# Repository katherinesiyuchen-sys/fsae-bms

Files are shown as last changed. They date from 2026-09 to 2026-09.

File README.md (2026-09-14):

# fsae-bms

*Doing this for the love of the game 🏎️*

Centralized battery management board for one **6S segment** of Energus 1s4p Li-ion modules.

## Cell voltage

Six cells in series stack up. Only cell 1 has a terminal at 0 V:

```
cell 6   18.0 V ── 21.6 V
cell 1      0 V ──  3.6 V
```

An ADC measures relative to its own ground and reads 0–3.3 V. Cell 6's top sits at 21.6 V, so we cannot wire it to a pin and measuring both ends and subtracting means finding a 3.6 V answer from two ~20 V readings, with all the error from both landing on the difference.

**A flying capacitor removes the pedestal mechanically.** Two ADG1408 muxes, addressed together with inputs offset by one tap, connect a 1 µF capacitor across the selected cell. The mux then disconnects both ends — the capacitor holds the cell's voltage with no memory of its former potential — and a second mux state presents it to the ADC as an ordinary ground-referenced source.

All six cells travel one signal path, so there is **one** gain error and **one** offset, common to all of them. In the cell-to-cell comparison balancing depends on, a common error largely cancels.

Rejected: a divider stack (error from both taps lands in full on a 3 V result), and six high-common-mode difference amplifiers (6× cost, six independent gain errors to trim).

### Channel map

Each mux has 8 channels; six cells use six, and the spare two do real work.

| Address | U1 — cap top | U2 — cap bottom | Phase |
|---|---|---|---|
| 0–5 | `CELL2`–`CELL7` | `CELL1`–`CELL6` | charge from cell 1–6 |
| 6 | `SELFTEST` | `GNDA` | known voltage through the chain |
| 7 | ADC divider | `GNDA` | read cap into ADC |

Address 7 *is* the transfer switch, so no second high-voltage switch is needed, and break-before-make — the property the mux was chosen for — protects the transfer too.
Address 6 verifies mux, capacitor, divider and reference every scan, before a cell reading is trusted. `SELFTEST` derives from `+3.3VA`, **not** `VREF`, so a reference failure cannot hide itself.

## Temperature 

The Energus module's built-in sensor is a **temperature-variable voltage shunt reference**, behaving like a zener whose voltage falls with temperature.

| Property | Consequence |
|---|---|
| Needs a **680 Ω pull-up**, not a divider | ~2.2 mA bias per channel |
| 2.44 V @ −40 °C → 1.30 V @ +120 °C, non-linear | datasheet lookup table, no β equation |
| **Galvanically isolated** from cell terminals | reads ground-referenced — no mux, no level shift |
| 4 sensors per module, analogue-OR'd | reports the module hot spot — 100 % coverage against a 30 % requirement |
| Shunt reference, not a ratio | reading largely immune to rail variation |

Six channels diode-OR into `TEMP_HOT`. Because sensor voltage *falls* with temperature, the hottest module is the lowest voltage, so a common-anode Schottky array extracts the minimum and one comparator watches all six.

**The diode drop is an error and it sets the threshold.** `TEMP_HOT` = lowest sensor + V_f, about 0.2 V at 154 µA, varying ±50 mV. At −11 mV/°C that's ±4.5 °C. So the hardware trip is aimed at **57 °C** to absorb the spread, and firmware, which reads all six channels individually, owns the precise per-module limit. Layered by design: the comparator is the backstop that works with firmware dead.

```
threshold  1.534 V (57 C) + 0.2 V Vf  =  1.734 V
divider    R18 662R / R19 1.50k from VREF
check      1.5 / 2.162 x 2.5  =  1.734 V
```

`TSENSE_RTN` returns to `GNDA`, not `GND`: you're measuring a voltage across the sensor relative to its own return, and the ADC measures relative to `VSSA`. The ~13 mA of sensor current in the analog ground is DC, so it's a fixed offset rather than noise.

---

## Protection 

A hung microcontroller that hasn't noticed an overvoltage is *indistinguishable* from a healthy one that sees nothing wrong. Both are silent. So the trip cannot depend on code
executing and the rules agree: the shutdown circuit must be latched open by non-programmable logic, resettable only by a person at the vehicle. **SW1, never a GPIO.**

| Source | Threshold | At | Gated |
|---|---|---|---|
| Overvoltage | 2.096 V | 4.192 V cell | address 7 only |
| Undervoltage | 1.246 V | 2.493 V cell | address 7 only |
| Overtemperature | 1.734 V | 57 °C | continuous |
| Watchdog timeout | ~200 ms | kicked every 20 ms | continuous |

`VCELL` is only a real cell voltage during the read slot — every other slot the divider
node is mid-transfer. So the voltage comparators are gated by an address decode, and one
gate does the whole job:

```
NOR(/ADDR7, VFAULT_N)  =  ADDR7 . fault
```

Both signals are active-low, and NOR is the AND of two active-low inputs.

All four thresholds derive from `VREF` — the same reference the ADC's scale is corrected against — so hardware trip points and firmware measurements can never disagree about what 4.2 V means.

**The fail-safe is structural.** The relay's normally-open contact sits in the shutdown circuit, held closed only while the latch says healthy *and* 12 V is present. A fault, a dead latch, a lost rail, an undriven gate. Every one gives coil de-energized, contact open, circuit broken. Q1's gate pulldown guarantees the last of those.

---

## Balancing

Passive dissipative, one optocoupler and one BSS138 per cell. The optocoupler solves a level-shift problem: cell 6's FET source sits ~21 V above ground, and a MOSFET switches on V_GS, gate voltage relative to *its own source*. A ground-referenced 3.3 V drive reads as −21 V to that gate.

```
LED     (3.3 - 1.2) / 470R  =  4.5 mA
opto    CTR ~50%            ->  ~2.2 mA available
gate    4.2 V / 101k        =  42 uA needed      (50x margin)
        -> phototransistor saturates, Vgs ~ 3.96 V

bleed   4.2 V / 100R  =  42 mA
        0.176 W per cell  ·  1.06 W all six  ·  1206 rated 0.25 W
```

100 Ω rather than 50 Ω halves current and dissipation — consistent with the argument below that heat is the binding constraint, not balance time. Shedding ~200 mAh at 42 mA takes about five hours, which is normal: balancing happens on the charger between sessions, not on track.

### Active balancing was evaluated and rejected

Without a dedicated controller the options are a switched-capacitor shuttle (a signal mux can't carry useful balance current, so it needs a second HV switch matrix whose timing must never overlap the first), adjacent-cell inductive buck-boost (five half-bridges with isolated gate drive, moving charge one hop at a time), or multi-winding flyback (custom magnetics).

Against that: active balancing recovers a fraction of the *imbalance* order 1–2 % of capacity at ~80 % transfer efficiency. And the problem passive balancing actually causes in a sealed accumulator is **heat**, better solved by limiting how many cells bleed at once. 

What would change the answer: a longer event, a thermally-limited pack, or a production vehicle where round-trip efficiency compounds over thousands of cycles.

---

### Buses

```
CELL[1..7]    cell taps -> frontend, balance
BAL_EN[1..6]  mcu -> balance
TSENSE[1..6]  J2 -> temp
TEMP[1..6]    temp -> mcu
FE_CTL        {MUX_A0 MUX_A1 MUX_A2 MUX_EN}
PROT          {WDT_KICK FAULT_N}
CAN           {CAN_TX CAN_RX}
SWD           {SWDIO SWCLK SWO NRST}
```

Bus aliases live in `feb-bms.kicad_pro`, so open the **project**, not individual sheets, or
they won't resolve.

## Key parts

| Ref | Part | Role | Datasheet |
|---|---|---|---|
| U1, U2 | ADG1408YRUZ | 8:1 analog mux, break-before-make | [ADI](https://www.analog.com/media/en/technical-documentation/data-sheets/ADG1408_1409.pdf) |
| U4 | LM339 | quad comparator, open collector | [ST](https://www.st.com/resource/en/datasheet/lm139.pdf) |
| U3/U5/U6/U7/U8/U11 | 74LVC1G10 / 1G02 / 1G32 | gating and latch | [TI](https://www.ti.com/lit/ds/symlink/sn74lvc1g02.pdf) |
| U9 | TPS3823-33 | watchdog supervisor | [TI](https://www.ti.com/lit/ds/symlink/tps3823.pdf) |
| U10 | ADR4525 | 2.500 V reference | [ADI](https://www.analog.com/media/en/technical-documentation/data-sheets/ADR4520_4525_4530_4533_4540_4550.pdf) |
| U18 | STM32F446RETx | LQFP64 | [ST](https://www.st.com/resource/en/datasheet/stm32f446re.pdf) |
| U19 | TJA1051T/3 | CAN transceiver, VIO = 3.3 V | [NXP](http://www.nxp.com/docs/en/data-sheet/TJA1051.pdf) |
| U20 | AP63203WU | 12 V → 5 V buck | [Diodes](https://www.diodes.com/assets/Datasheets/AP63200-AP63201-AP63203-AP63205.pdf) |
| U21 | MIC5219-3.3 | 5 V → 3.3 V LDO, low noise | [Microchip](http://ww1.microchip.com/downloads/en/DeviceDoc/MIC5219-500mA-Peak-Output-LDO-Regulator-DS20006021A.pdf) |
| U22 | TPS61040 | 12 V → 28 V boost | [TI](http://www.ti.com/lit/ds/symlink/tps61040.pdf) |
| Q1, Q2, Q3–Q8 | BSS138 | relay / lamp / balance | [onsemi](https://www.onsemi.com/pub/Collateral/BSS138-D.PDF) |
| Q9 | AO3401A | reverse-polarity blocker | [AOS](http://www.aosmd.com/pdfs/datasheet/AO3401A.pdf) |
| U12–U17 | LTV-817S | balance gate drive, isolated | [Liteon](http://www.us.liteon.com/downloads/LTV-817-827-847.PDF) |
| D3–D5 | BAT54A | diode-OR, common anode | [Diodes](http://www.diodes.com/_files/datasheets/ds11005.pdf) |
| D10 | SMAJ16A | load-dump clamp, unidirectional | [Littelfuse](https://www.littelfuse.com/media?itemid=75e32973-b177-4ee3-a0ff-cedaf1abdb93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) |
| K1 | SPDT relay | NO contact in the SDC | — |

## Compliance

Requirements below are from the **Formula Student 2026 rules v1.1**. The clause numbers
still need re-deriving from the FSAE rulebook — same requirements, different numbering.

| Requirement | Where it lands |
|---|---|
| Measure all cell voltages, TS current, ≥30 % of cell temps | 6 cells scanned; module sensors cover 100 %. **TS current is not on this board** — open question whether a segment board carries it |
| Max cell temp 60 °C or datasheet, whichever lower | 45 °C is binding while charging |
| Open SDC on persistent fault: >500 ms voltage, >1 s temp | 145 ms scan |
| Red latching cockpit "AMS" lamp | driven from the latch, not firmware |
| Loss of a measurement connection must open SDC | self-test slot + implausible-reading detection |
| Faults individually injectable for inspection | break-in header — **to add** |
| SDC latched by non-programmable logic, manual reset | SR latch + SW1 |
| De-energized state opens SDC | NO relay contact throughout |

## Opening this

KiCad 10.0.3. Open **`feb-bms.kicad_pro`**.

## Presentation

Full deck: [BMS.pdf](BMS.pdf) · source: [BMS.pptx](BMS.pptx)

| | |
|---|---|
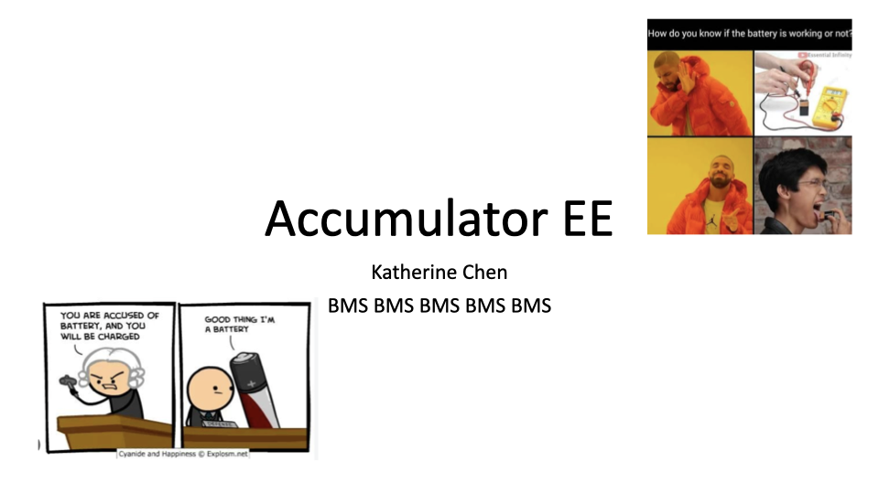
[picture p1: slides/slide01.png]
1 – Title
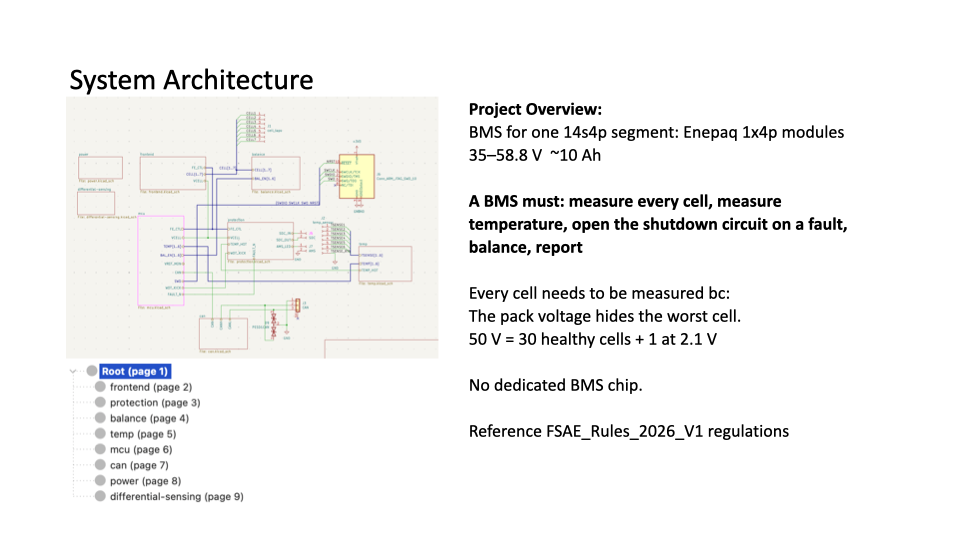
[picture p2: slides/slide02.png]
2 – System architecture
|  |  |
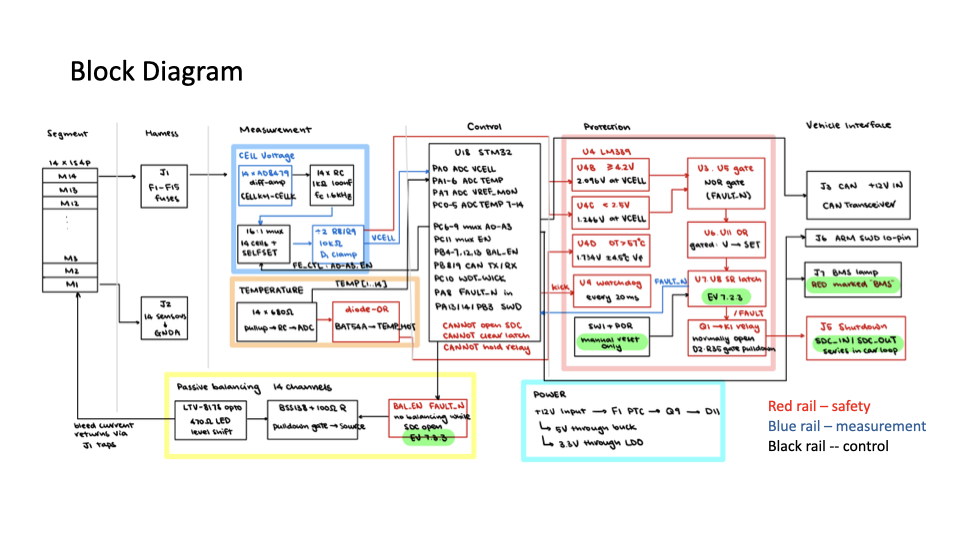
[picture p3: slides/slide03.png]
3 – Block diagram
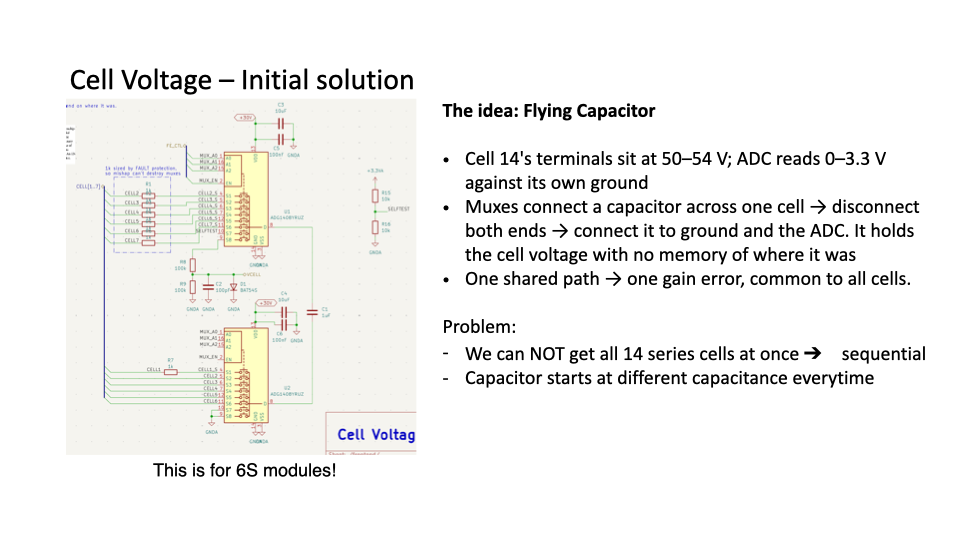
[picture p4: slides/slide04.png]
4 – Cell voltage: flying capacitor
|  |  |
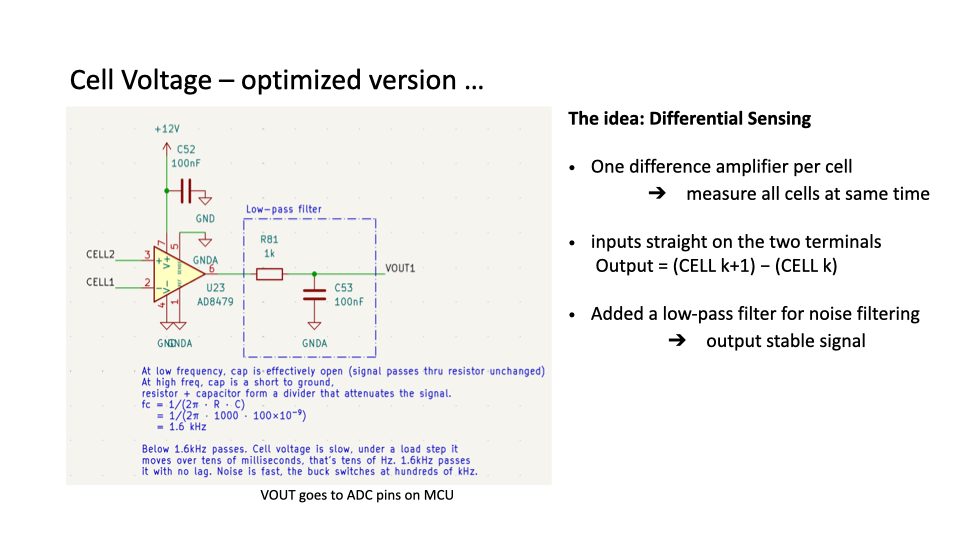
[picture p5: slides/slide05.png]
5 – Cell voltage: differential amplifier
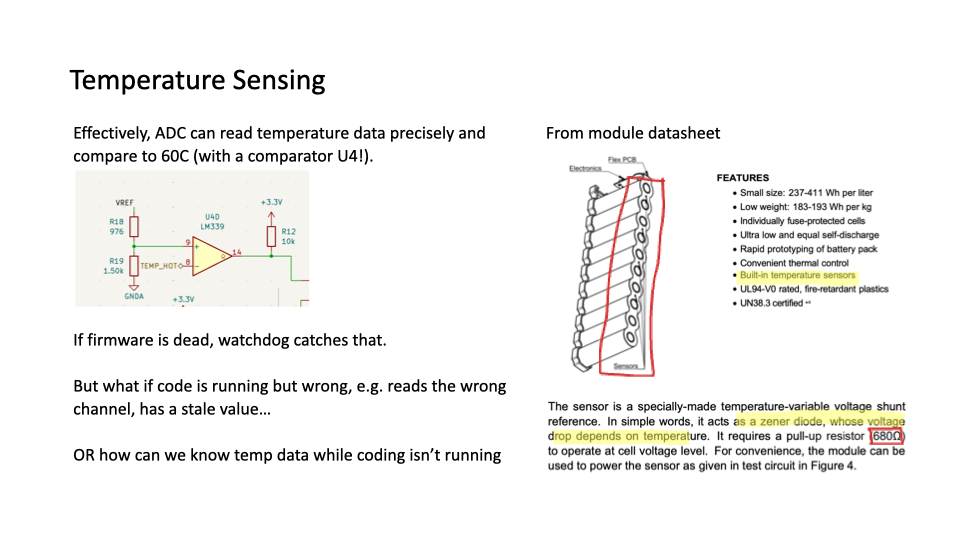
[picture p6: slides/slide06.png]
6 – Temperature sensing
|  |  |
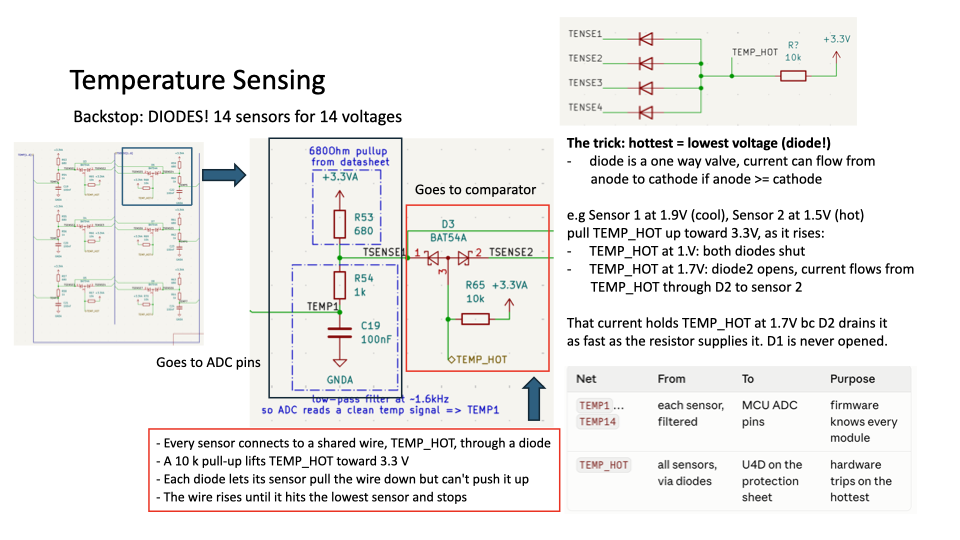
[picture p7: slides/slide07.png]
7 – Temperature sensing: diode-OR
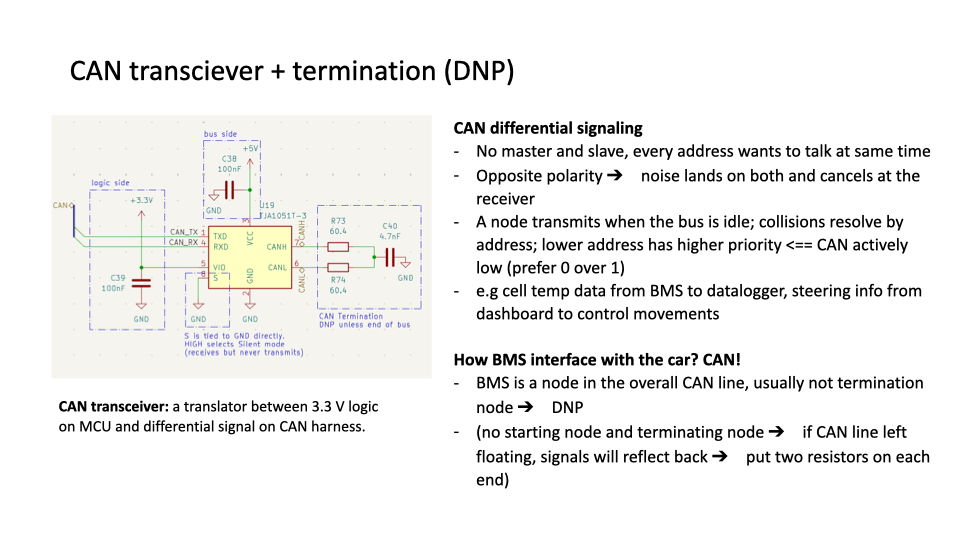
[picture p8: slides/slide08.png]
8 – CAN transceiver + termination
|  |  |
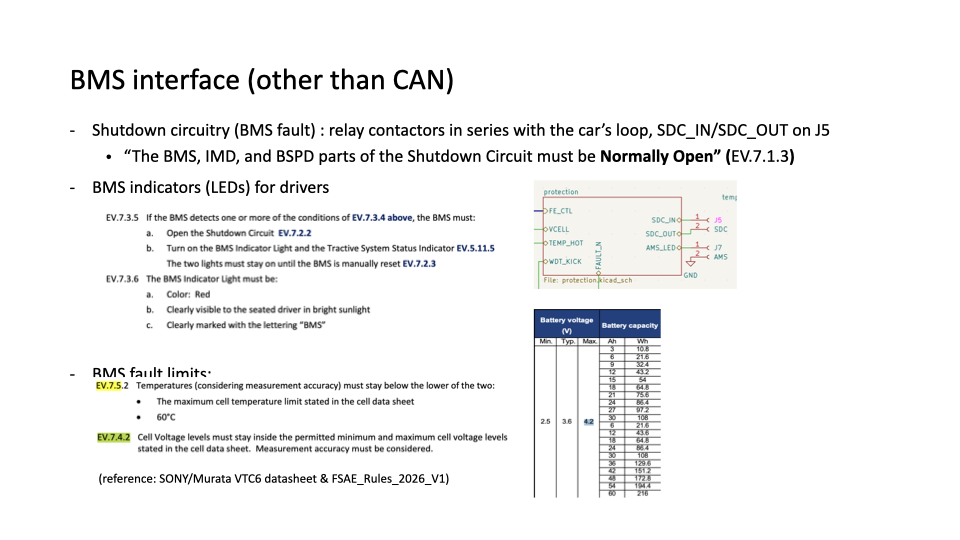
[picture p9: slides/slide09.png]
9 – BMS interface to the car
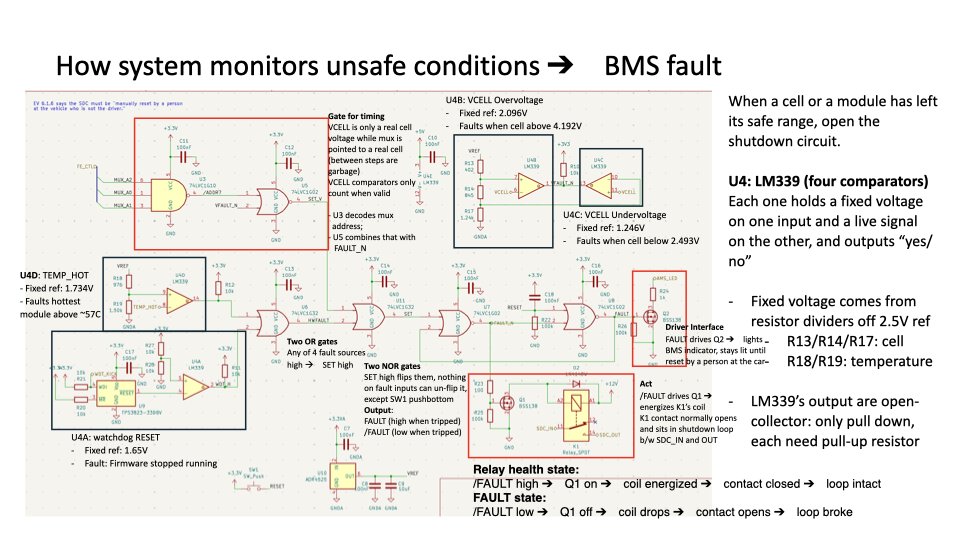
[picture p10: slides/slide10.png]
10 – Unsafe-condition monitoring → BMS fault
|  |  |
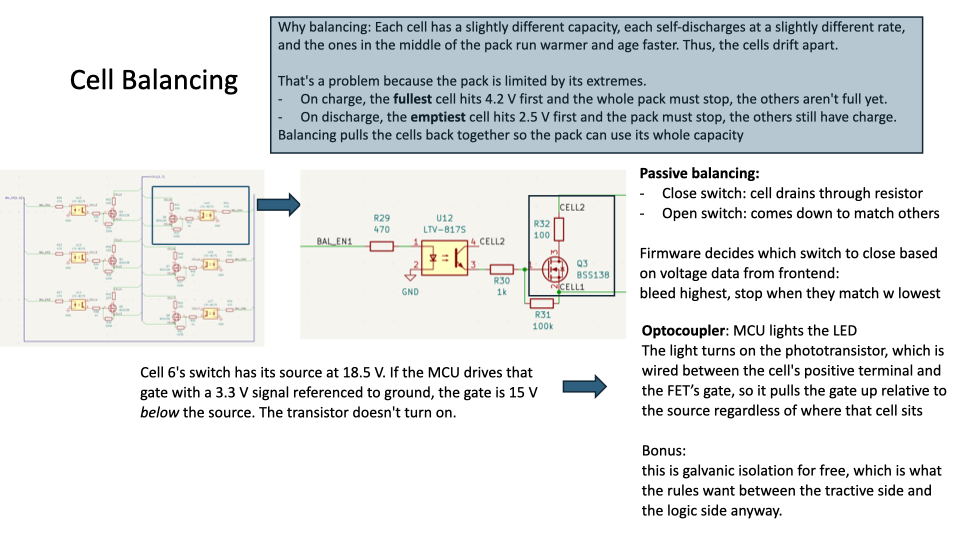
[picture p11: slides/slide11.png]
11 – Cell balancing
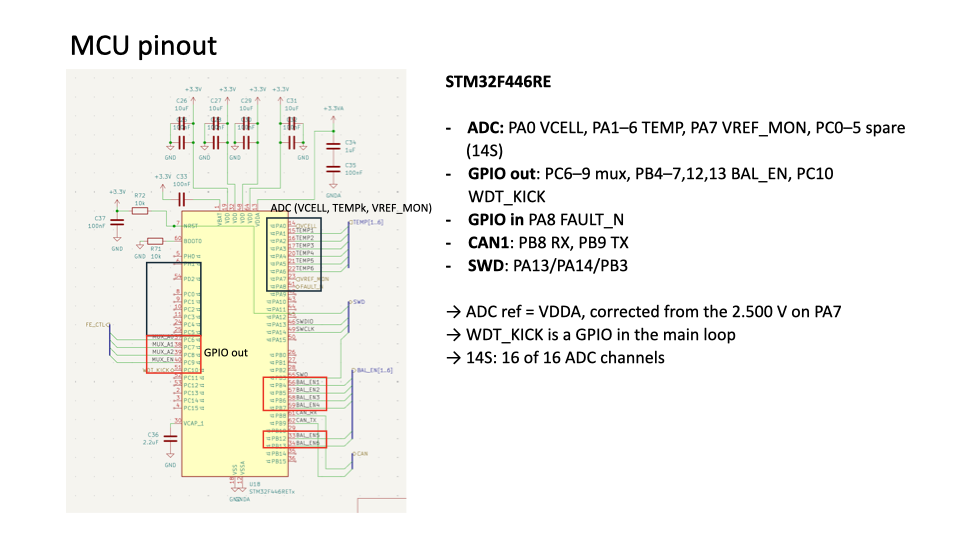
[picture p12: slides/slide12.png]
12 – MCU pinout
|  |  |
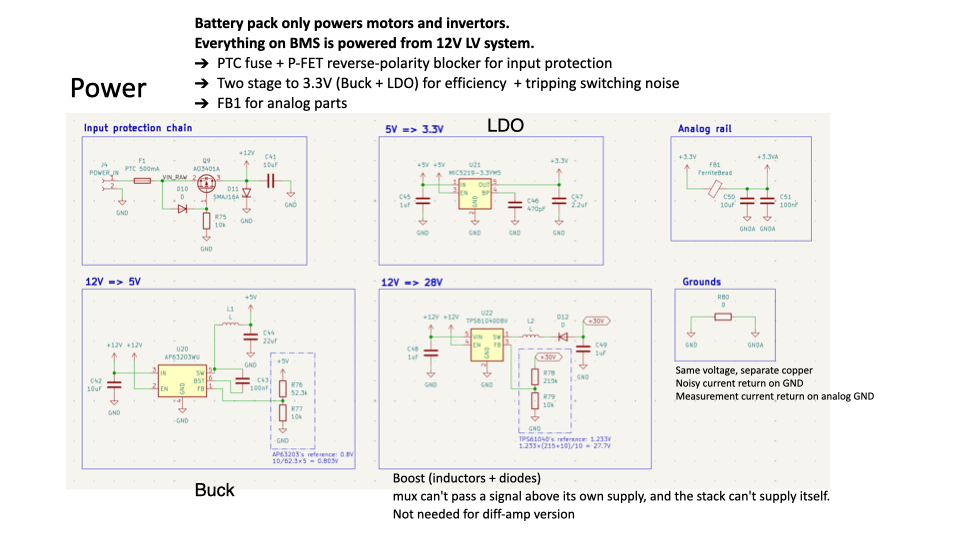
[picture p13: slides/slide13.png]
13 – Power
|  | |

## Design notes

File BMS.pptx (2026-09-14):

## Accumulator EE

Katherine Chen
BMS BMS BMS BMS BMS

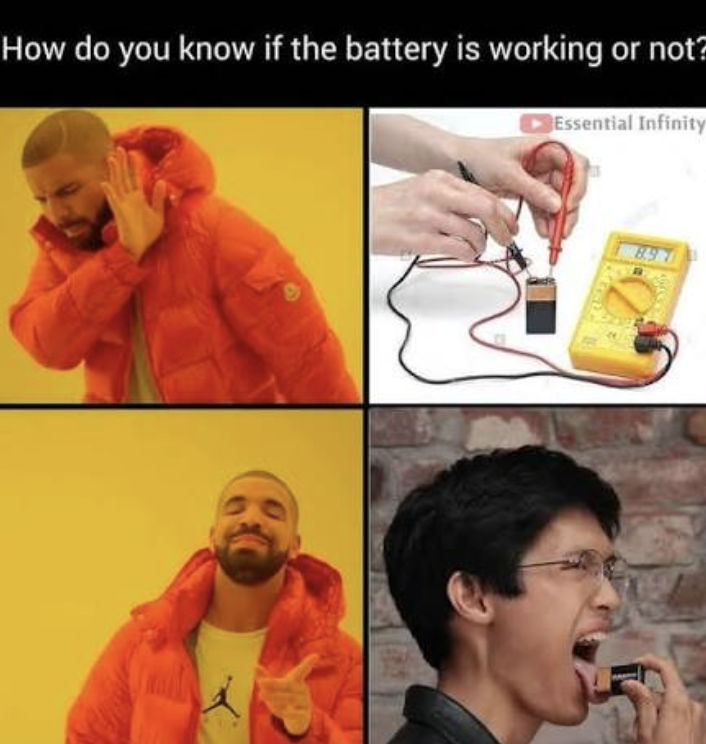
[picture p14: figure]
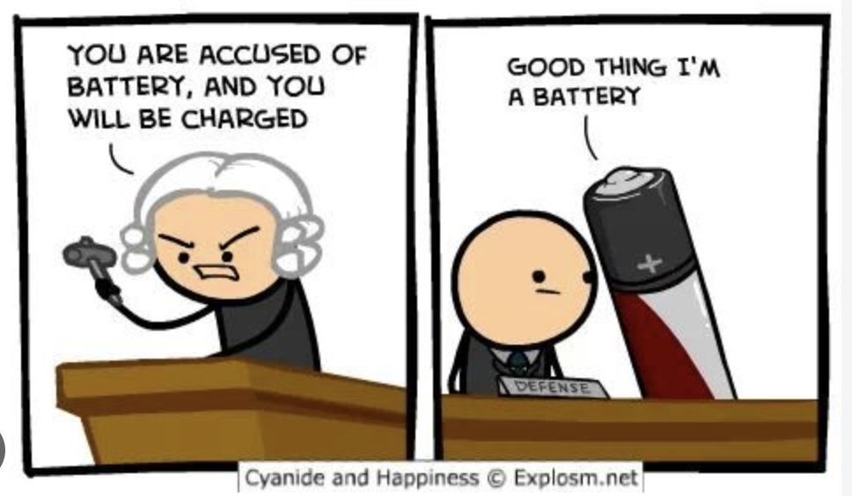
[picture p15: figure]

## System Architecture

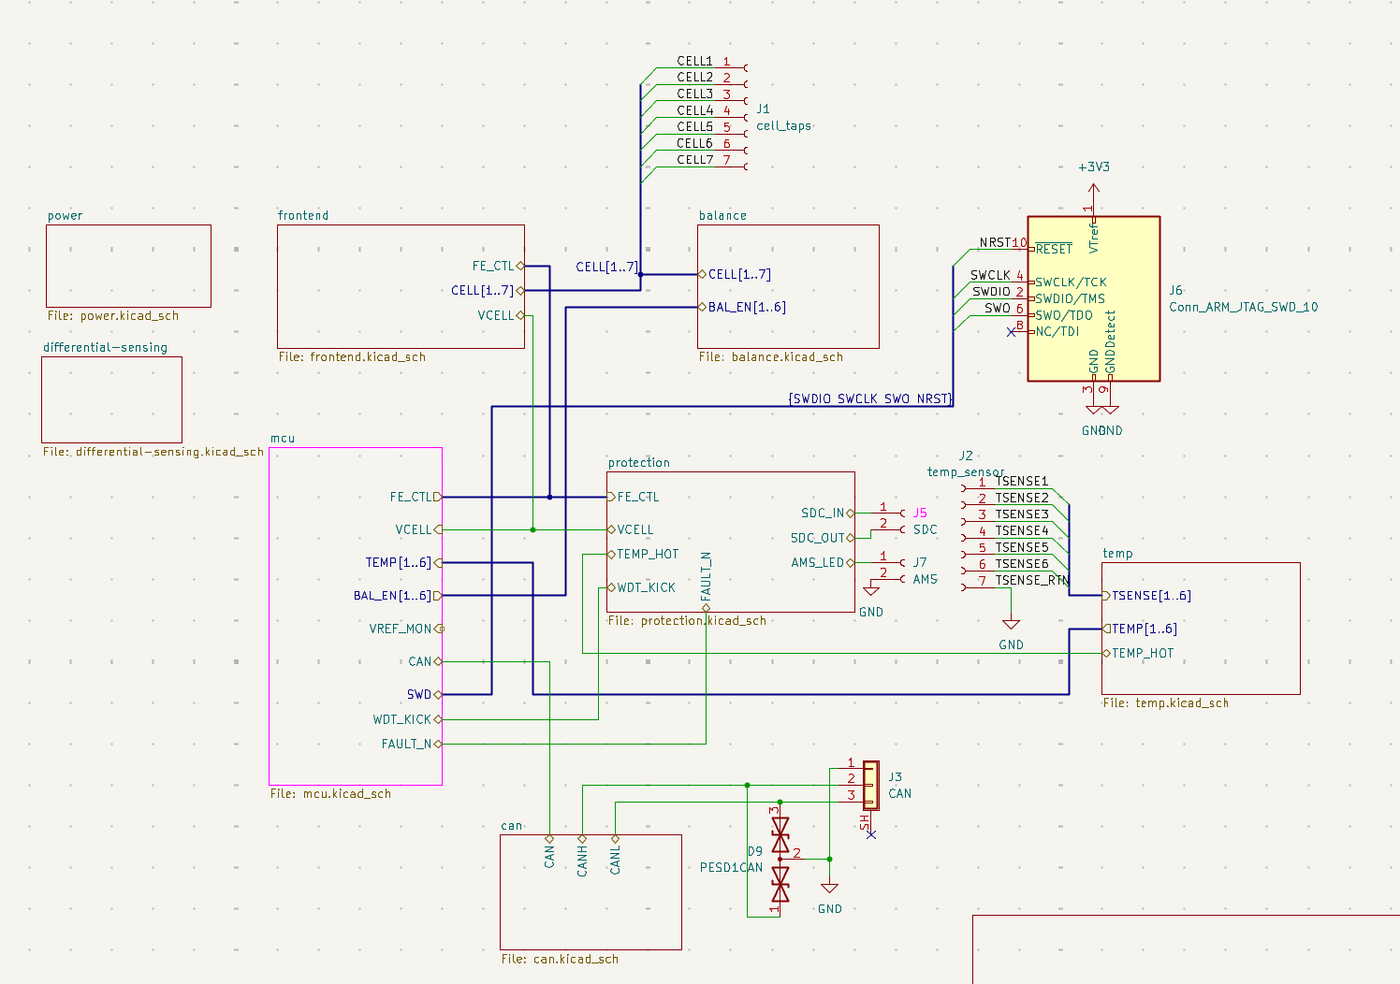
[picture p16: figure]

Project Overview:
BMS for one 14s4p segment: Enepaq 1x4p modules 35–58.8 V ~10 Ah
A BMS must: measure every cell, measure temperature, open the shutdown circuit on a fault, balance, report
Every cell needs to be measured bc:
The pack voltage hides the worst cell.
50 V = 30 healthy cells + 1 at 2.1 V
No dedicated BMS chip.
Reference FSAE_Rules_2026_V1 regulations

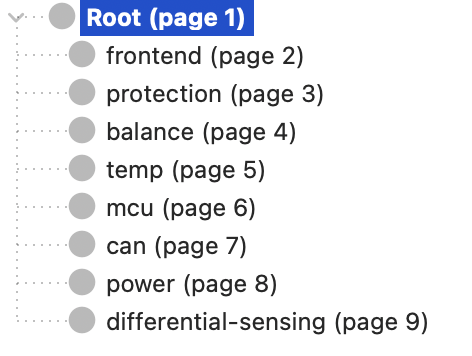
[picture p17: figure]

## Block Diagram

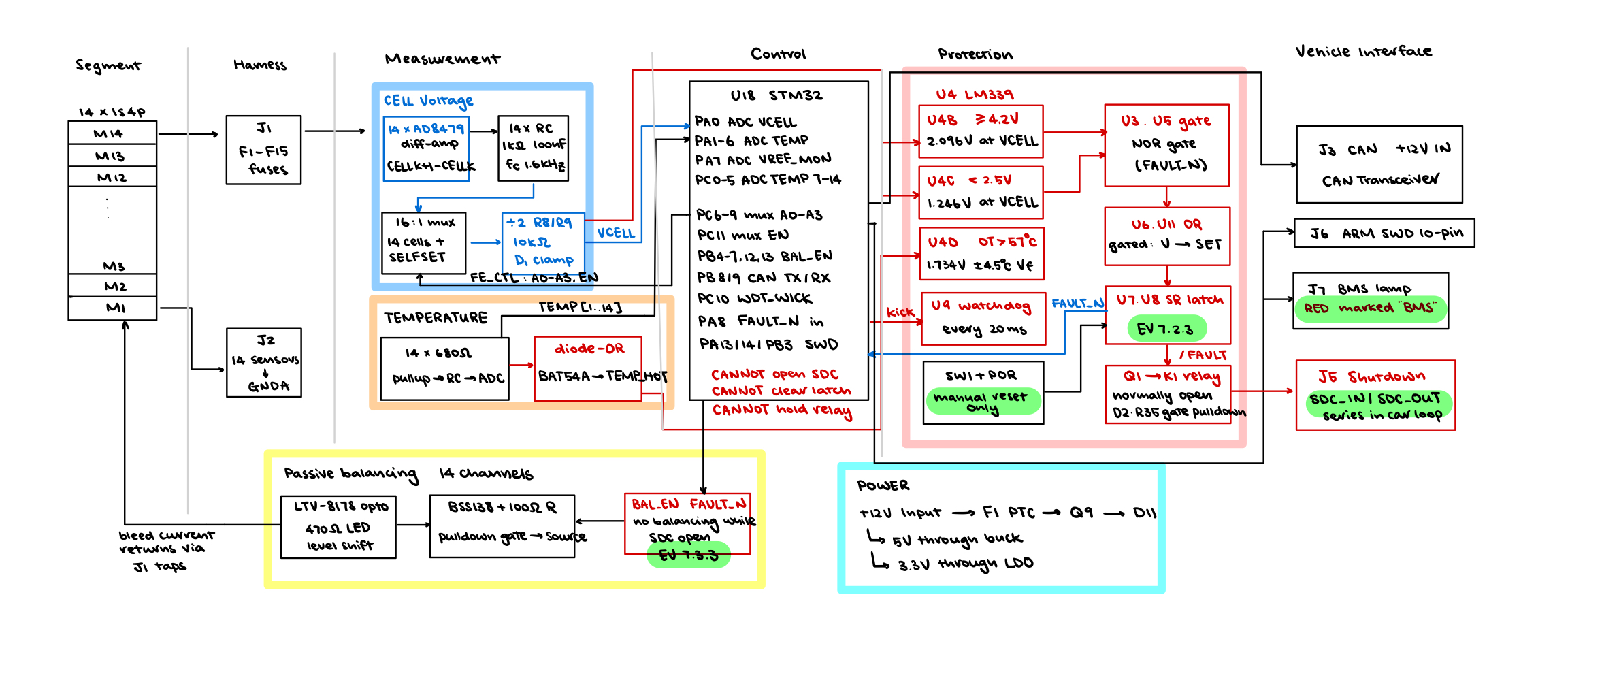
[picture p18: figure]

Red rail – safety
Blue rail – measurement
Black rail -- control

## Cell Voltage – Initial solution

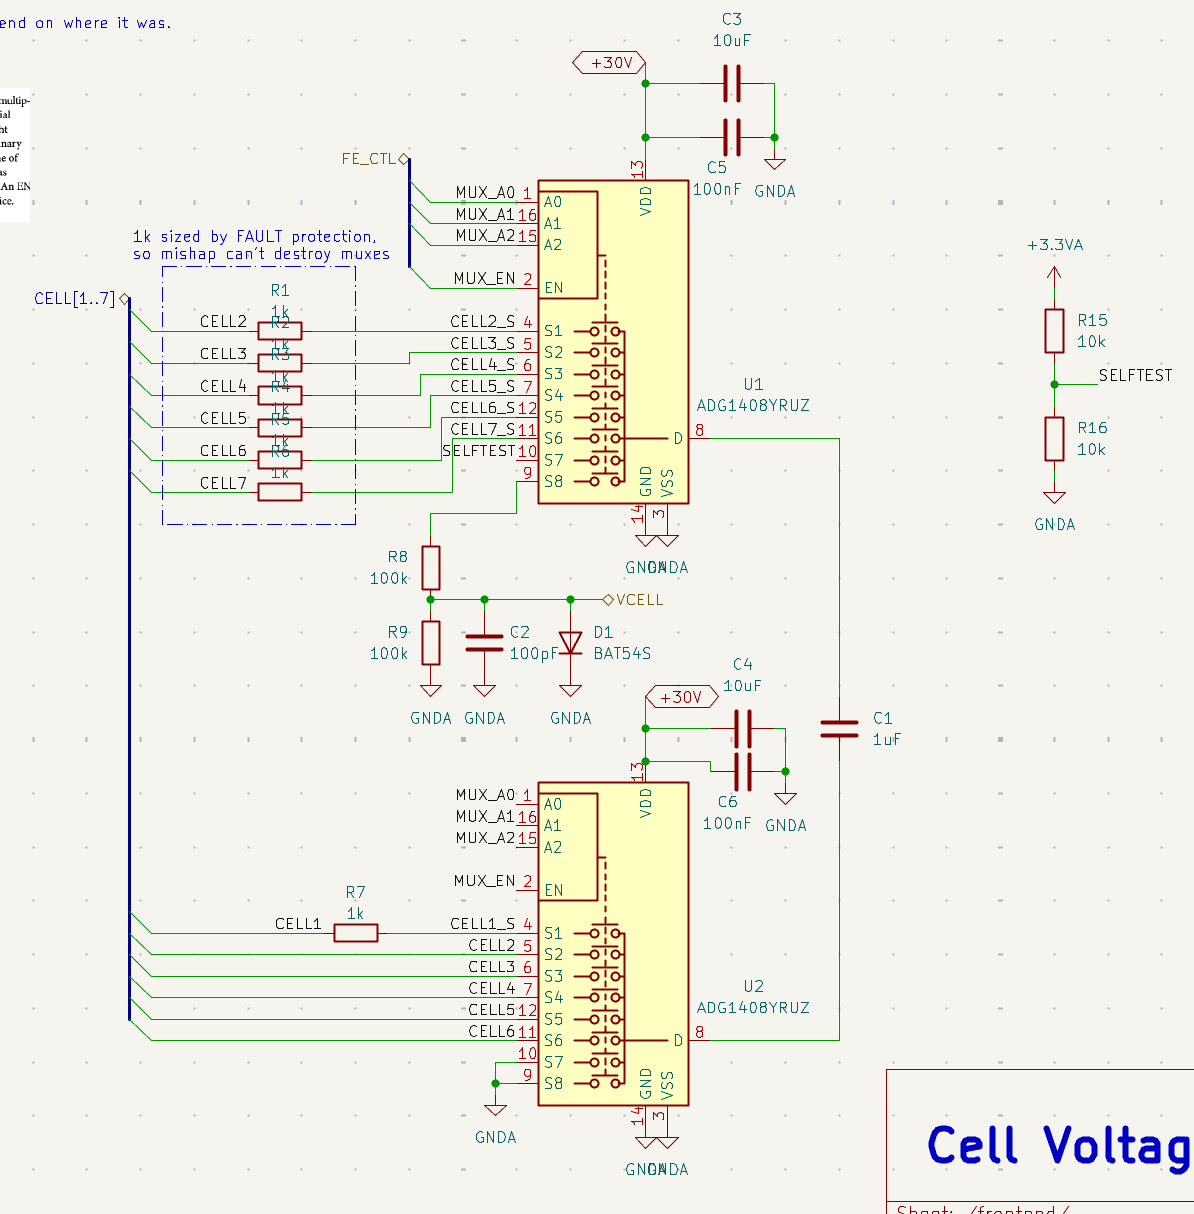
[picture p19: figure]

This is for 6S modules!

The idea: Flying Capacitor
- Cell 14's terminals sit at 50–54 V; ADC reads 0–3.3 V against its own ground
- Muxes connect a capacitor across one cell → disconnect both ends → connect it to ground and the ADC. It holds the cell voltage with no memory of where it was
- One shared path → one gain error, common to all cells.
Problem:
- We can NOT get all 14 series cells at once → sequential
- Capacitor starts at different capacitance everytime

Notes: multiplexer - selector switch

## Cell Voltage – optimized version …

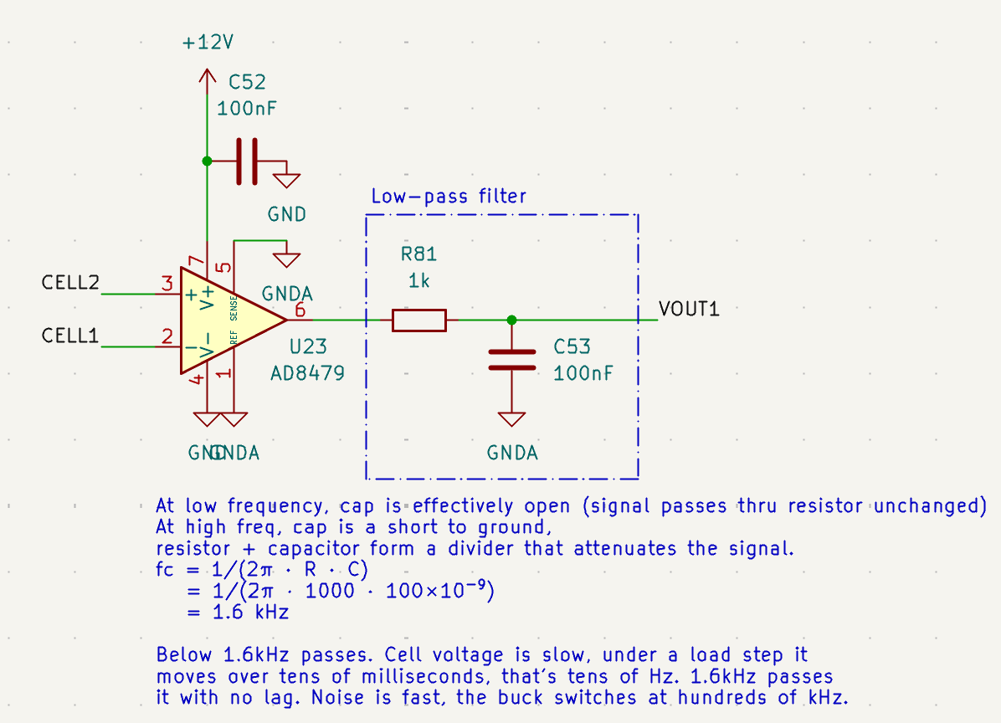
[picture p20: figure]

The idea: Differential Sensing
- One difference amplifier per cell
→ measure all cells at same time
- inputs straight on the two terminals
Output = (CELL k+1) − (CELL k)
- Added a low-pass filter for noise filtering
→ output stable signal

VOUT goes to ADC pins on MCU

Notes:
There are two ways to measure voltage:
Single ended: measure one point against ground -- ADC pins
Differential: measure the gap between two points, and don’t care about where either one is relative to ground

## Temperature Sensing

Effectively, ADC can read temperature data precisely and compare to 60C (with a comparator U4!).
If firmware is dead, watchdog catches that.
But what if code is running but wrong, e.g. reads the wrong channel, has a stale value…
OR how can we know temp data while coding isn’t running

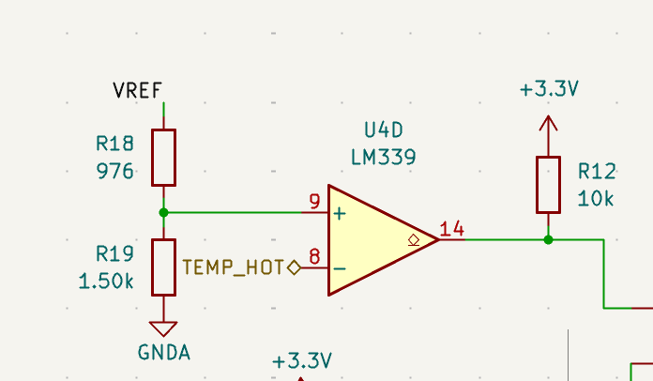
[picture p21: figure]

From module datasheet

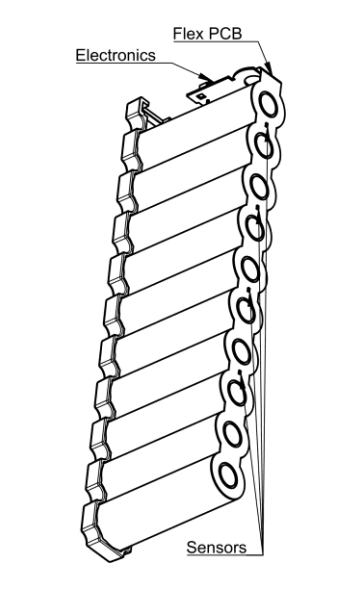
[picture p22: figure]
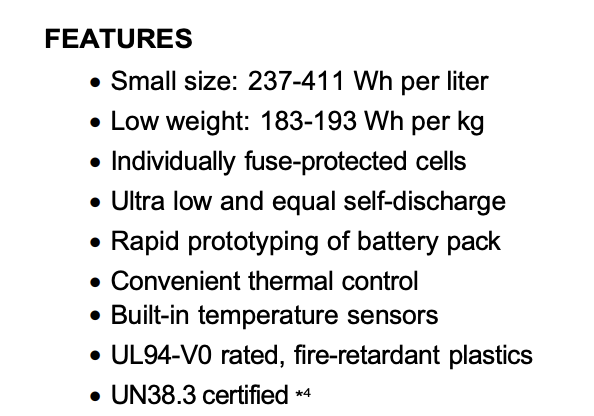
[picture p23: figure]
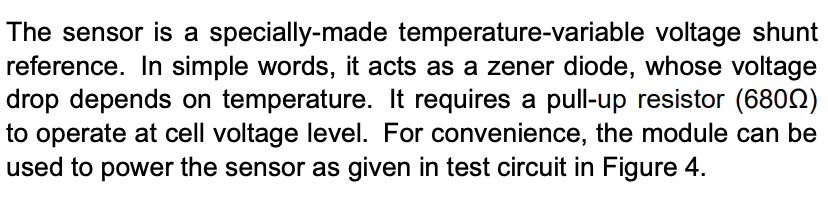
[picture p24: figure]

## Temperature Sensing

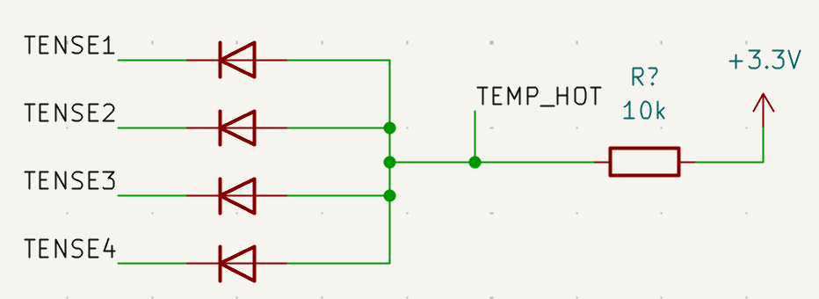
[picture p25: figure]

The trick: hottest = lowest voltage (diode!)
- diode is a one way valve, current can flow from
anode to cathode if anode >= cathode
e.g Sensor 1 at 1.9V (cool), Sensor 2 at 1.5V (hot)
pull TEMP_HOT up toward 3.3V, as it rises:
- TEMP_HOT at 1.V: both diodes shut
- TEMP_HOT at 1.7V: diode2 opens, current flows from
TEMP_HOT through D2 to sensor 2
That current holds TEMP_HOT at 1.7V bc D2 drains it
as fast as the resistor supplies it. D1 is never opened.

Backstop: DIODES! 14 sensors for 14 voltages

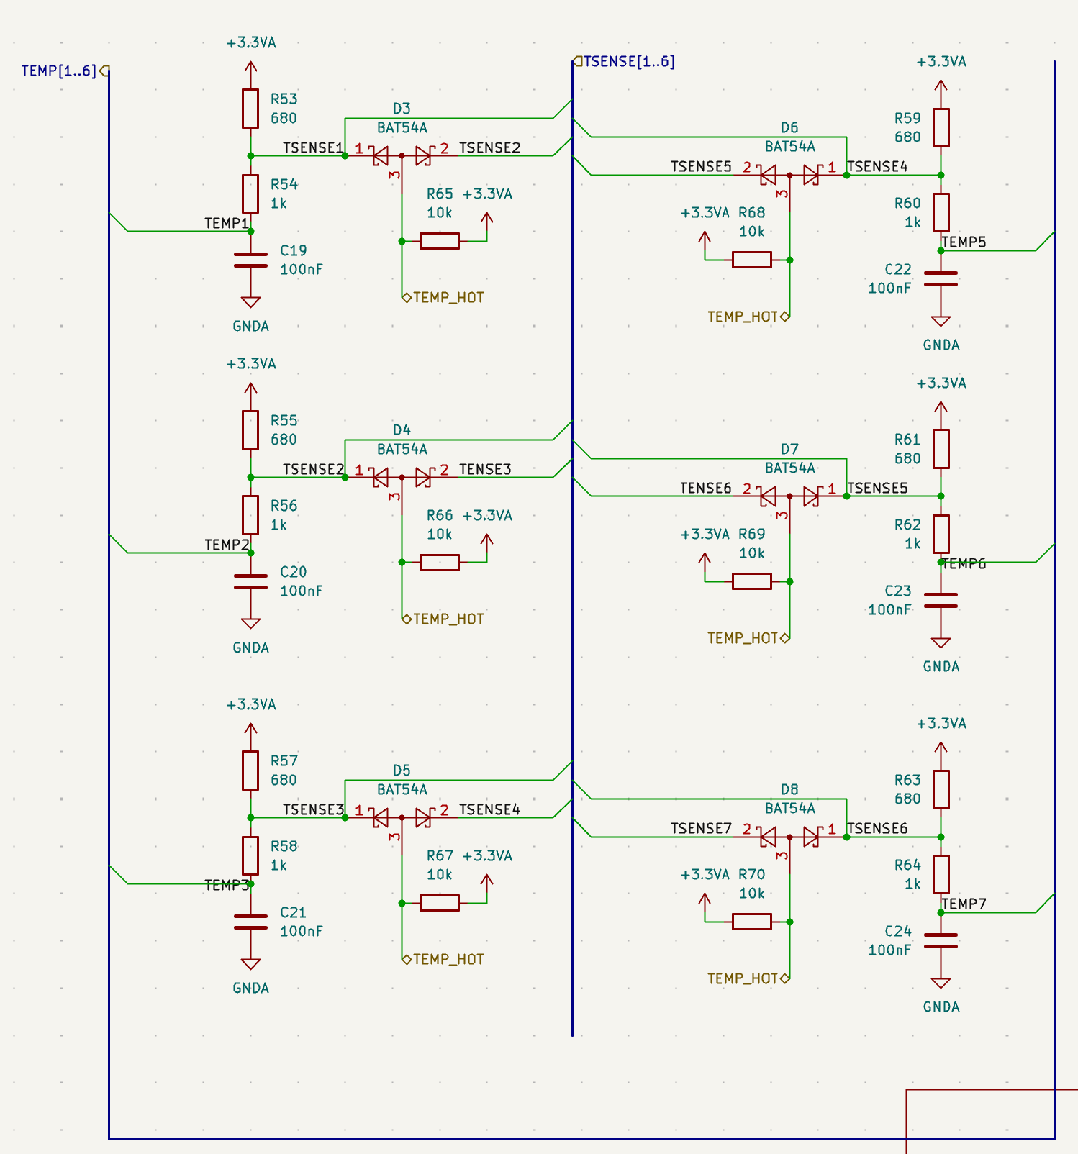
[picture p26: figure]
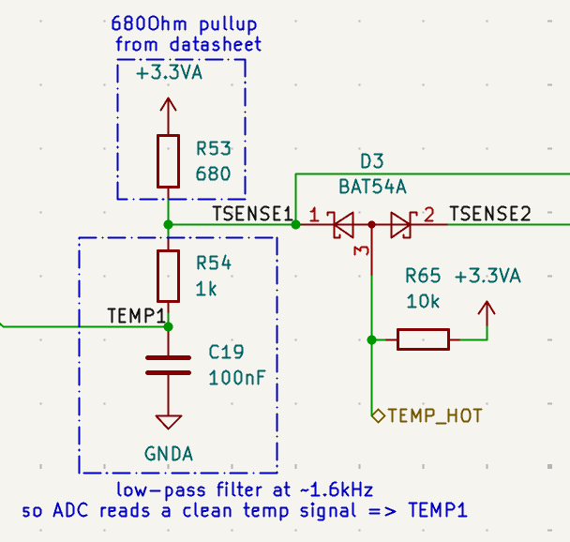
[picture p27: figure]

Goes to comparator

Goes to ADC pins

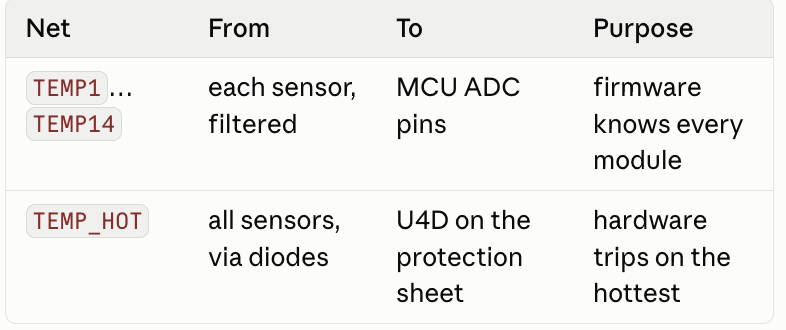
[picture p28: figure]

- Every sensor connects to a shared wire, TEMP_HOT, through a diode
- A 10 k pull-up lifts TEMP_HOT toward 3.3 V
- Each diode lets its sensor pull the wire down but can't push it up
- The wire rises until it hits the lowest sensor and stops

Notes: Every sensor connects to a shared wire, TEMP_HOT, through a diode — anode on the shared wire, cathode on the sensor. A 10 k pull-up lifts TEMP_HOT toward 3.3 V. Each diode lets its sensor pull the wire down but can't push it up. So the wire rises until it hits the lowest sensor and stops
one of the diodes opens first and voltage holds at that level bc diode drains it as fast as resistor supplies it

## CAN transciever + termination (DNP)

CAN differential signaling
- No master and slave, every address wants to talk at same time
- Opposite polarity → noise lands on both and cancels at the receiver
- A node transmits when the bus is idle; collisions resolve by address; lower address has higher priority <== CAN actively low (prefer 0 over 1)
- e.g cell temp data from BMS to datalogger, steering info from dashboard to control movements
How BMS interface with the car? CAN!
- BMS is a node in the overall CAN line, usually not termination node → DNP
- (no starting node and terminating node → if CAN line left floating, signals will reflect back → put two resistors on each end)

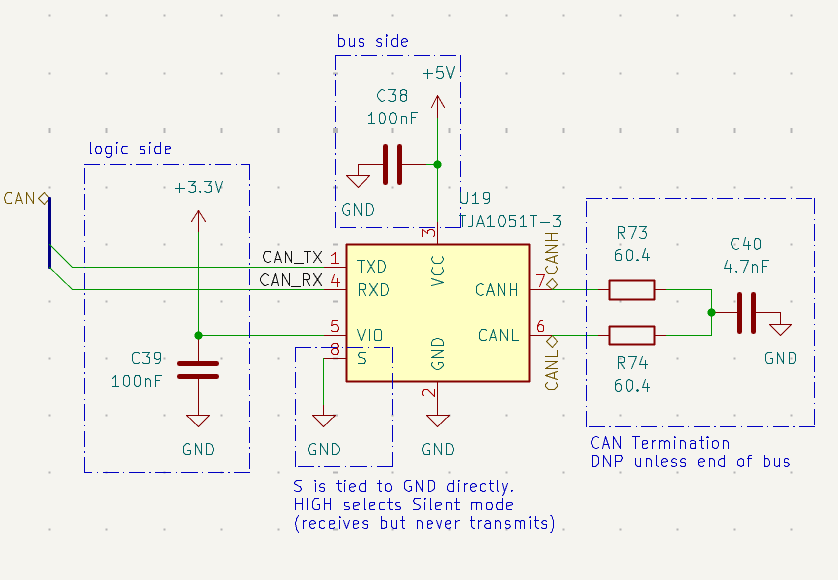
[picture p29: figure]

CAN transceiver: a translator between 3.3 V logic
on MCU and differential signal on CAN harness.

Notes: Because the microcontroller speaks CAN logic but can't drive CAN wire.

## BMS interface (other than CAN)

- Shutdown circuitry (BMS fault) : relay contactors in series with the car’s loop, SDC_IN/SDC_OUT on J5
  - “The BMS, IMD, and BSPD parts of the Shutdown Circuit must be Normally Open” (EV.7.1.3)
- BMS indicators (LEDs) for drivers
- BMS fault limits:

(reference: SONY/Murata VTC6 datasheet & FSAE_Rules_2026_V1)

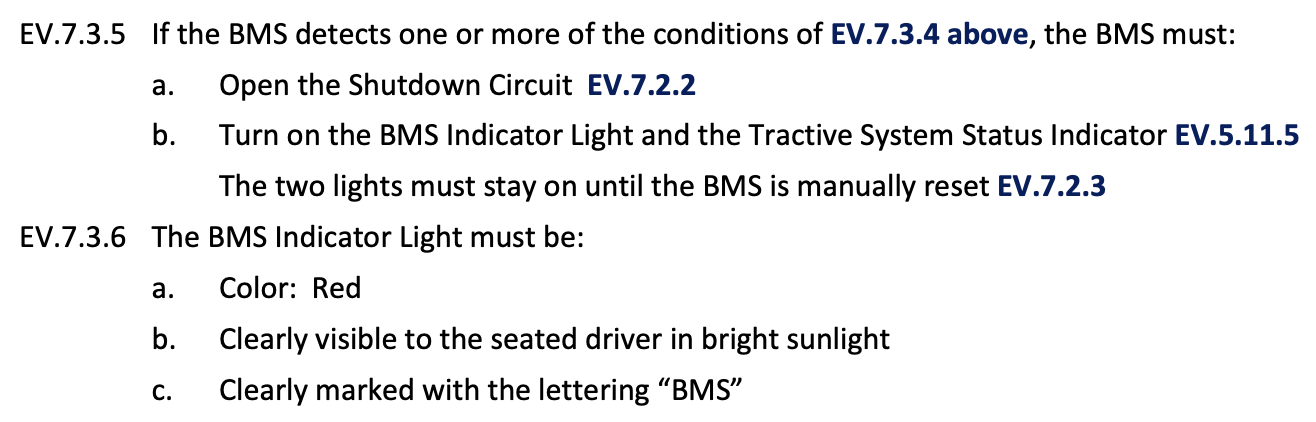
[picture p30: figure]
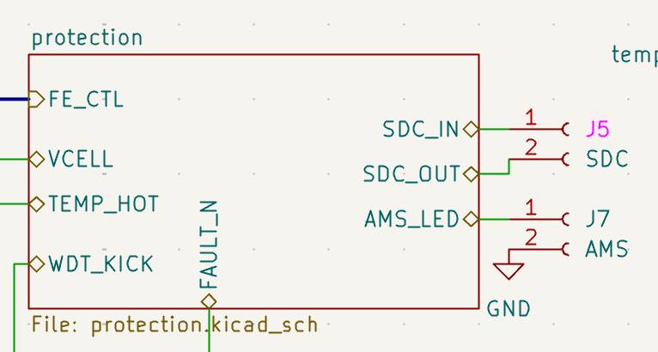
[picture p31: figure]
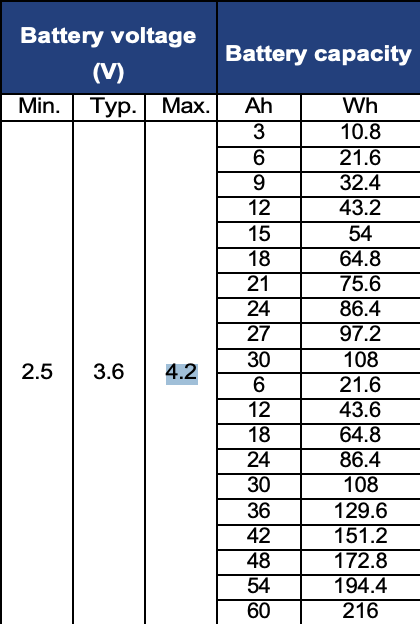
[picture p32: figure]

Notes: relay contactors opens car loop

for regulation compliance

## How system monitors unsafe conditions → BMS fault

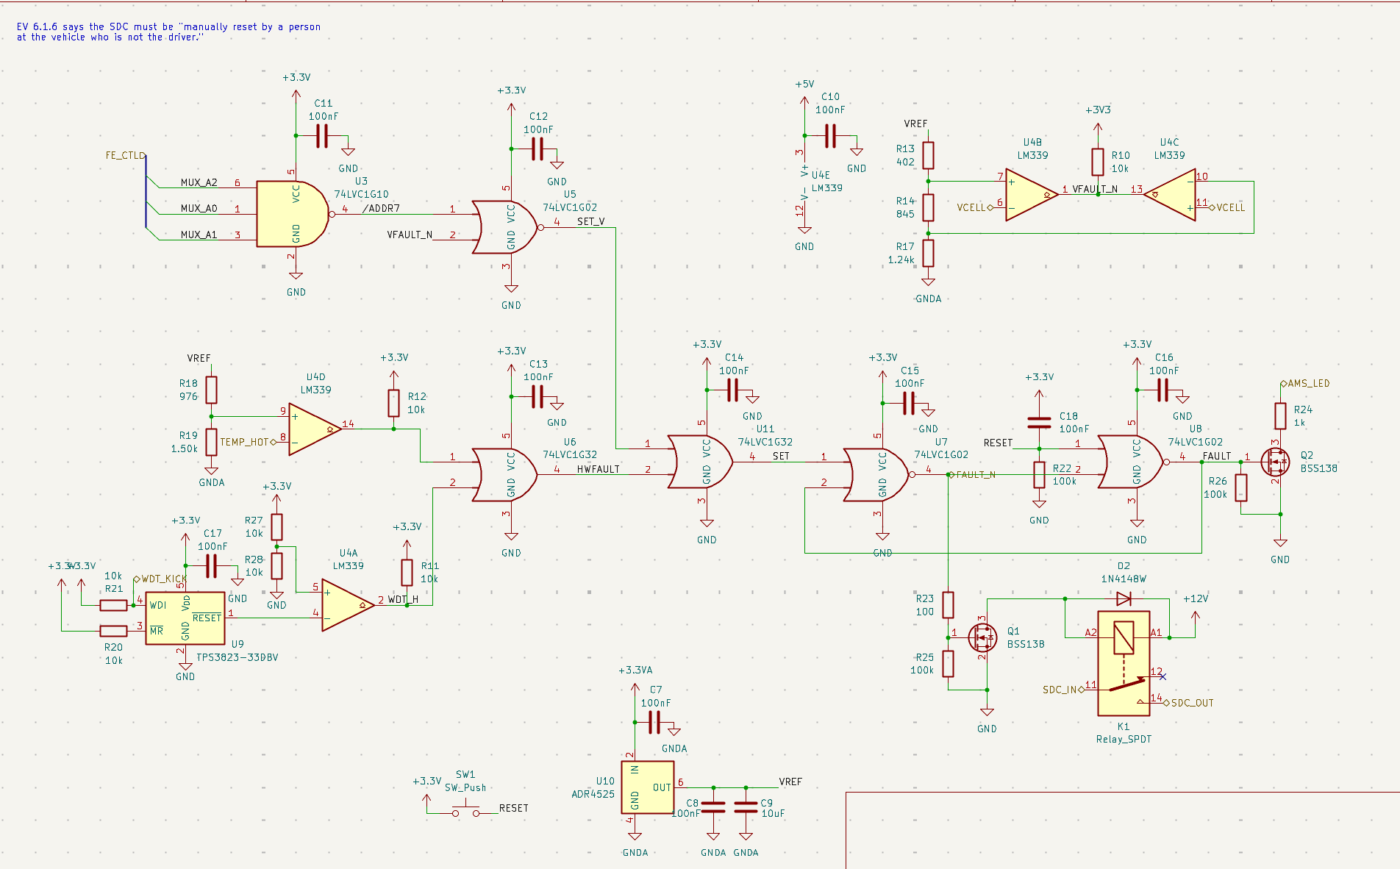
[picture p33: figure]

Gate for timing
VCELL is only a real cell voltage while mux is pointed to a real cell (between steps are garbage)
VCELL comparators only count when valid
- U3 decodes mux
address;
- U5 combines that with
FAULT_N

U4B: VCELL Overvoltage
- Fixed ref: 2.096V
- Faults when cell above 4.192V

When a cell or a module has left its safe range, open the shutdown circuit.
U4: LM339 (four comparators)
Each one holds a fixed voltage on one input and a live signal on the other, and outputs “yes/no”
- Fixed voltage comes from resistor dividers off 2.5V ref
  - R13/R14/R17: cell
  - R18/R19: temperature
- LM339’s output are open-collector: only pull down, each need pull-up resistor

U4C: VCELL Undervoltage
- Fixed ref: 1.246V
- Faults when cell below 2.493V

U4D: TEMP_HOT
- Fixed ref: 1.734V
- Faults hottest module above ~57C

U4A: watchdog RESET
- Fixed ref: 1.65V
- Fault: Firmware stopped running

Two OR gates
Any of 4 fault sources high → SET high

Two NOR gates
SET high flips them, nothing on fault inputs can un-flip it, except SW1 pushbottom
Output:
FAULT (high when tripped)
/FAULT (low when tripped)

Driver Interface
FAULT drives Q2 → lights BMS indicator, stays lit until reset by a person at the car

Act
/FAULT drives Q1 → energizes K1’s coil
K1 contact normally opens and sits in shutdown loop b/w SDC_IN and OUT

Relay health state:
/FAULT high → Q1 on → coil energized → contact closed → loop intact
FAULT state:
/FAULT low → Q1 off → coil drops → contact opens → loop broke

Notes: EV.7.2.3 says that once the BMS opens the shutdown circuit, it stays open until a person at the car manually resets it — and specifically, the driver can't do it from the seat, and neither the shutdown buttons nor the master switch can clear it.

Latch "not-fault" output sits at 3.3 V.

## Cell Balancing

Why balancing: Each cell has a slightly different capacity, each self-discharges at a slightly different rate,
and the ones in the middle of the pack run warmer and age faster. Thus, the cells drift apart.
That's a problem because the pack is limited by its extremes.
- On charge, the fullest cell hits 4.2 V first and the whole pack must stop, the others aren't full yet.
- On discharge, the emptiest cell hits 2.5 V first and the pack must stop, the others still have charge.
Balancing pulls the cells back together so the pack can use its whole capacity

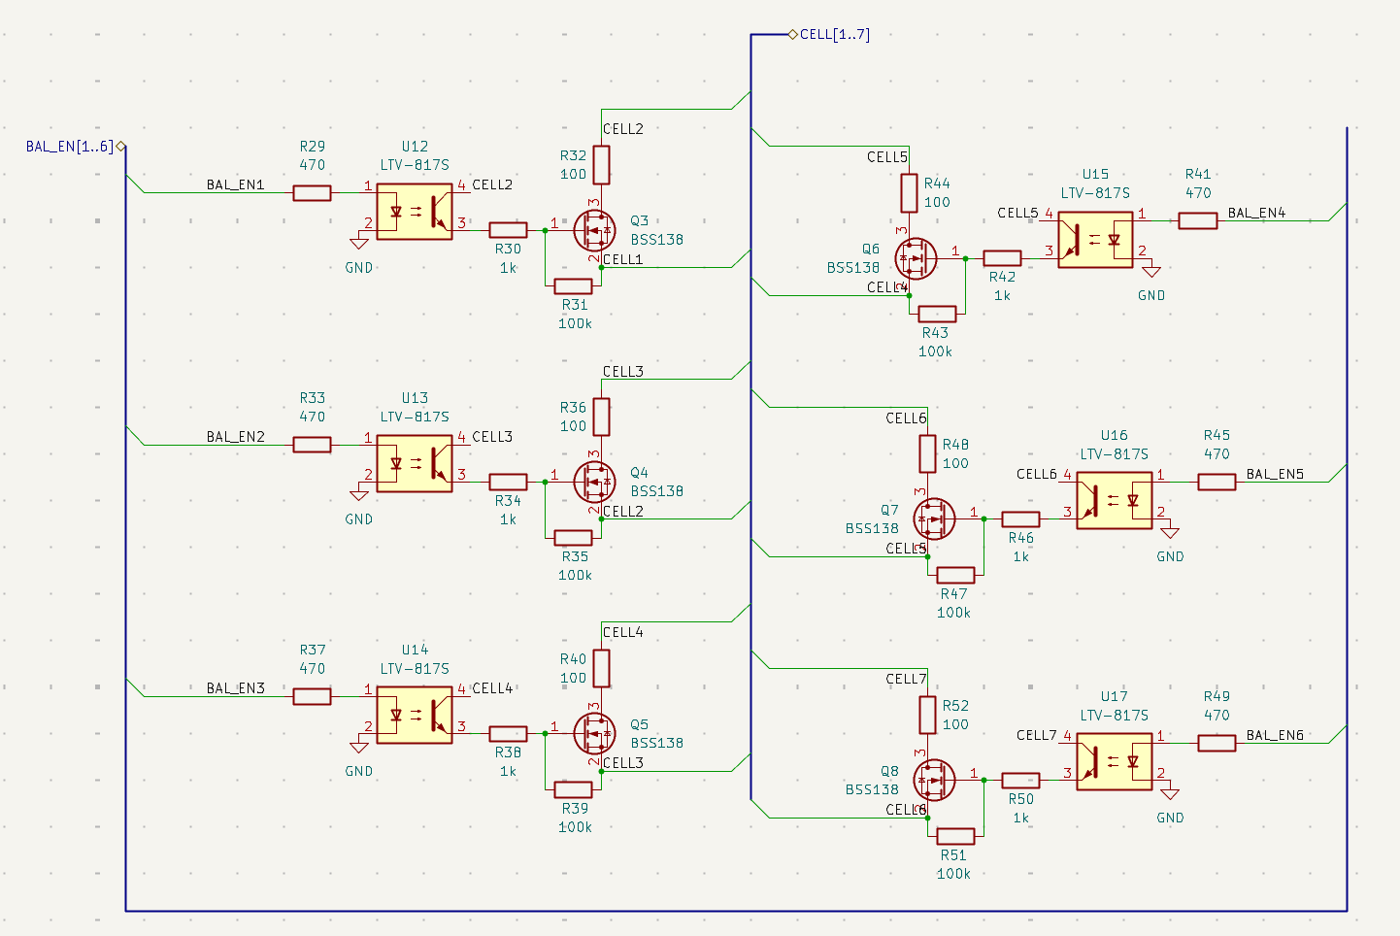
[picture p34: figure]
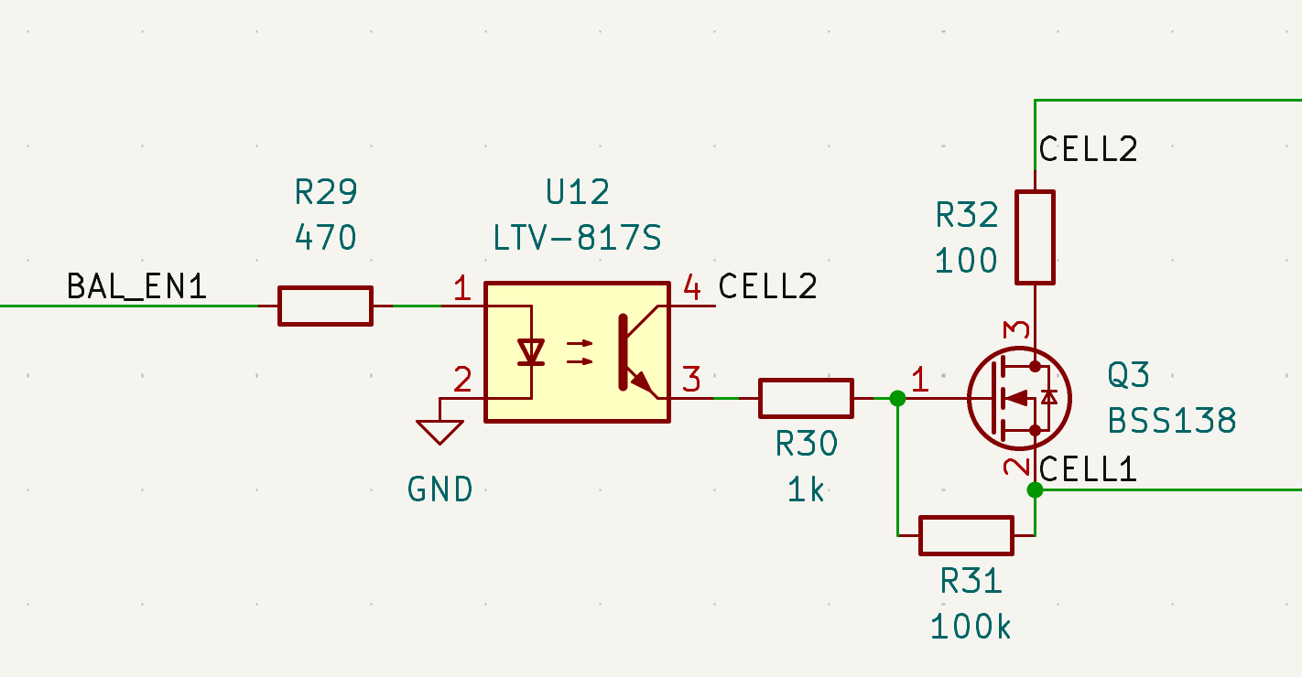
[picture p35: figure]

Cell 6's switch has its source at 18.5 V. If the MCU drives that
gate with a 3.3 V signal referenced to ground, the gate is 15 V
below the source. The transistor doesn't turn on.

Passive balancing:
- Close switch: cell drains through resistor
- Open switch: comes down to match others
Firmware decides which switch to close based on voltage data from frontend:
bleed highest, stop when they match w lowest

Optocoupler: MCU lights the LED
The light turns on the phototransistor, which is wired between the cell's positive terminal and the FET’s gate, so it pulls the gate up relative to the source regardless of where that cell sits
Bonus:
this is galvanic isolation for free, which is what the rules want between the tractive side and the logic side anyway.

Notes: Passive disspate heat: switch + resistor

Switched caps: A capacitor connected across a full cell charges up to its voltage.
Switch it across an empty cell; it's now higher than that cell, so it dumps charge in. Flip back and forth, thousands of times a second.

Pack-to-cell: feed a weak cell from the whole pack.

LTC3300

a DC/DC from the pack down to 12 V, then a constant-current buck routed to the weak cell through MOSFETs.

## MCU pinout

STM32F446RE
- ADC: PA0 VCELL, PA1–6 TEMP, PA7 VREF_MON, PC0–5 spare
(14S)
- GPIO out: PC6–9 mux, PB4–7,12,13 BAL_EN, PC10 WDT_KICK
- GPIO in PA8 FAULT_N
- CAN1: PB8 RX, PB9 TX
- SWD: PA13/PA14/PB3
→ ADC ref = VDDA, corrected from the 2.500 V on PA7
→ WDT_KICK is a GPIO in the main loop
→ 14S: 16 of 16 ADC channels

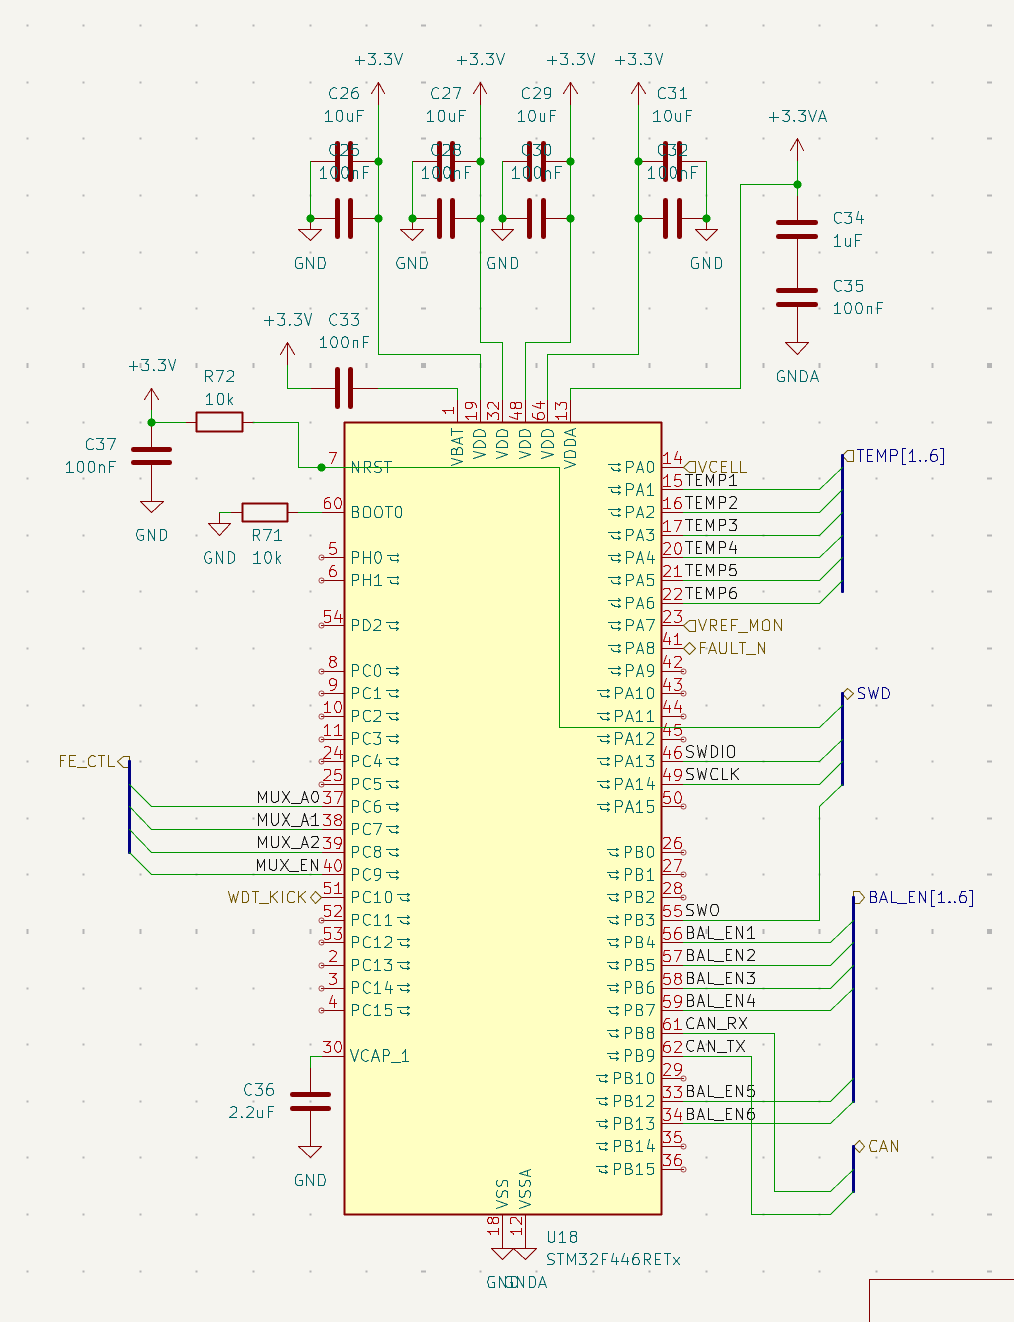
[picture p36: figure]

ADC (VCELL, TEMPk, VREF_MON)

GPIO out

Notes: VOUT1–14 → 16:1 mux → ÷2 → VCELL → PA0
Then the follow-up: "So it's still sequential?" sequenced by the ADC's ~20 µs sample time instead of a 20 ms capacitor settle.


Analog to digital converting:
ADC counts → volts (×2 for the divider)
ADC counts on the temperature pins → °C via the datasheet lookup table.

Balances. Finds the lowest cell, decides which are ahead, drives BAL_EN1–14, limits how many bleed at once, blanks the reading of a cell while it's bleeding, only balances when charging and when FAULT_N is high.

Sequences the measurement: Sets the mux address, waits, triggers the ADC, moves to the next cell.

What it explicitly does not do
Open the shutdown circuit — no pin exists for it
Clear the latch — SW1 only
Hold the relay closed — Q1 is driven by the latch, not by a GPIO

## Power

Battery pack only powers motors and invertors.
Everything on BMS is powered from 12V LV system.
- PTC fuse + P-FET reverse-polarity blocker for input protection
- Two stage to 3.3V (Buck + LDO) for efficiency + tripping switching noise
- FB1 for analog parts

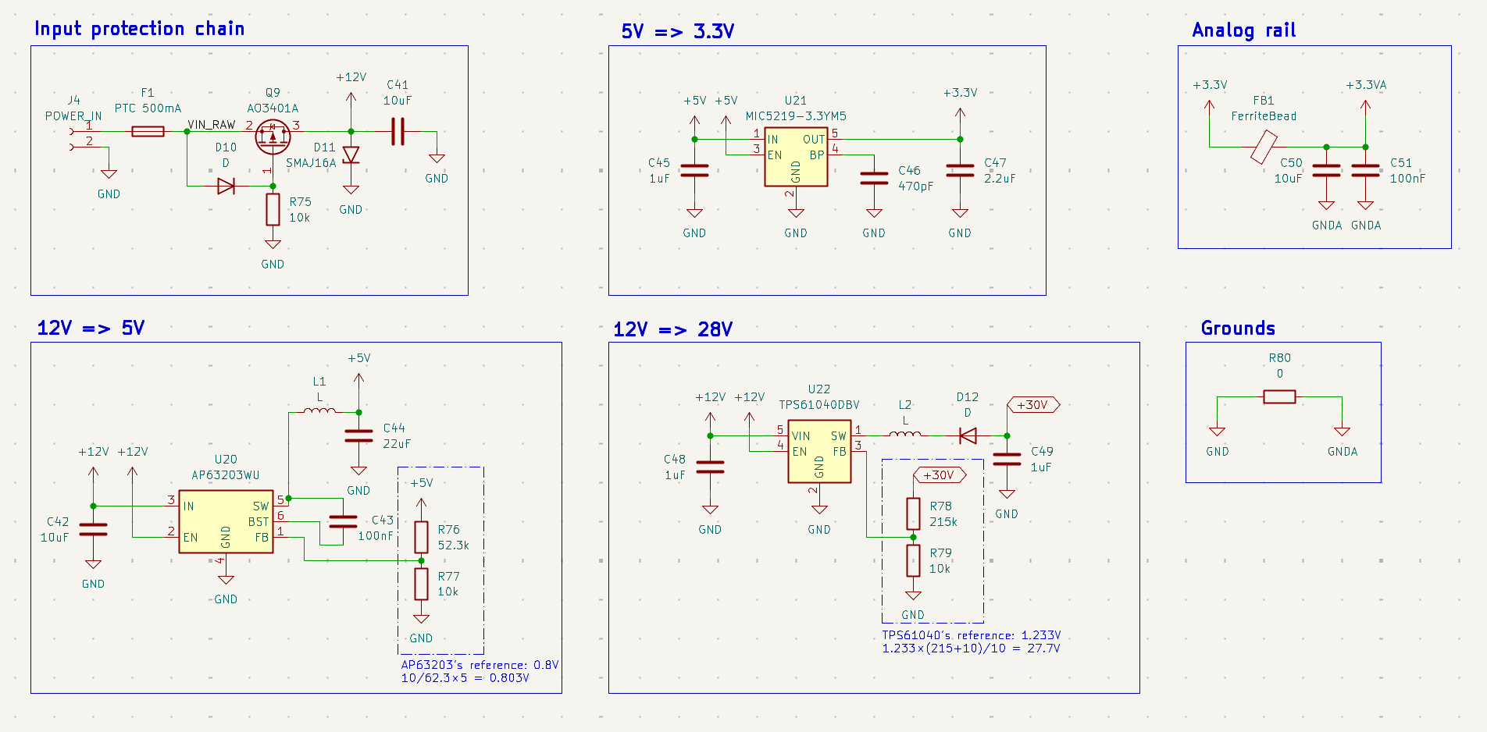
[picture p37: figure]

Boost (inductors + diodes)
mux can't pass a signal above its own supply, and the stack can't supply itself.
Not needed for diff-amp version

LDO

Same voltage, separate copper
Noisy current return on GND
Measurement current return on analog GND

Buck

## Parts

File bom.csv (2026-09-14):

Ref | Qty | Value | Footprint | Ordering code / spec | Why this part | Datasheet
C1,C34,C45,C48,C49 | 5 | 1uF | Capacitor_SMD:C_0603_1608Metric (C1: C_1210_3225Metric C0G) | C0G 50 V for C1 | C1 = flying capacitor: MUST be C0G or film (dielectric absorption, voltage coefficient). Others: VDDA / regulator caps.
C2 | 1 | 100pF | Capacitor_SMD:C_0603_1608Metric |  | ADC input cap at VCELL, C0G.
C3,C4,C9,C26,C27,C29,C31,C41,C42,C50 | 10 | 10uF | Capacitor_SMD:C_0805_2012Metric |  | Bulk on rails and mux VDD. GNDA-side ones return to GNDA.
C5,C6,C7,C8,C10,C11,C12,C13,C14,C15,C16,C17,C18,C19,C20,C21,C22,C23,C24,C25,C28,C30,C32,C33,C35,C37,C38,C39,C43,C51 | 30 | 100nF | Capacitor_SMD:C_0603_1608Metric |  | Decoupling, one per IC supply pin, at the pin. Analog ones return to GNDA.
C36,C47 | 2 | 2.2uF | Capacitor_SMD:C_0603_1608Metric |  | C36 VCAP_1 (STM32 core regulator — mandatory); C47 LDO output.
C40 | 1 | C | ASSIGN | 4.7nF DNP | C40 = 4.7 nF split-termination midpoint cap — DNP.
C44 | 1 | 22uF | Capacitor_SMD:C_1206_3216Metric |  | Buck output.
C46 | 1 | 470pF | Capacitor_SMD:C_0603_1608Metric |  | MIC5219 BYP pin — gives the low-noise spec.
D1 | 1 | BAT54S | Package_TO_SOT_SMD:SOT-23 | BAT54S | Series pair clamping VCELL to +3.3VA / GNDA — protects the ADC pin.
D2 | 1 | 1N4148W | Diode_SMD:D_SOD-123 | 1N4148W | Relay coil flyback diode, cathode to +12V. | https://www.vishay.com/docs/85748/1n4148w.pdf
D3,D4,D5,D6,D7,D8 | 6 | BAT54A | Package_TO_SOT_SMD:SOT-23 | BAT54A | Common-anode dual Schottky: diode-OR extracting the hottest module (lowest voltage). Only 3 needed — delete D6–D8. | http://www.diodes.com/_files/datasheets/ds11005.pdf
D9 | 1 | PESD1CAN | Package_TO_SOT_SMD:SOT-23 | PESD1CAN | Dual TVS across CANH/CANL to GND, placed at J3.
D10,D12 | 2 | D | ASSIGN | fill in | D10 = 12 V zener (Q9 gate clamp); D12 = 40 V Schottky boost diode (e.g. SS14). Set values.
D11 | 1 | SMAJ16A | Diode_SMD:D_SMA | SMAJ16A | Unidirectional TVS on 12 V input for load-dump transients. | https://www.littelfuse.com/media?itemid=75e32973-b177-4ee3-a0ff-cedaf1abdb93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
F1 | 1 | PTC 500mA | Fuse:Fuse_1812_4532Metric | 0ZCG0050AF2C | Resettable input fuse; CalSol precedent 0ZCG0050AF2C.
FB1 | 1 | FerriteBead | Inductor_SMD:L_0805_2012Metric |  | +3.3V → +3.3VA: one entry point to the quiet analog rail.
J1 | 1 | cell_taps | ASSIGN | DuraClik 7 | J1: 7-way keyed locking (Molex DuraClik, CalSol precedent); rated for balance current.
J2 | 1 | temp_sensor | ASSIGN | DuraClik 7 | J2: 7-way — 6 sensors + TSENSE_RTN to GNDA.
J3 | 1 | CAN | ASSIGN |  | J3: CAN + LV, shield one-end only.
J4 | 1 | POWER_IN | ASSIGN |  | J4: 12 V in.
J5 | 1 | SDC | ASSIGN |  | J5: shutdown circuit pass-through, SDC_IN / SDC_OUT.
J6 | 1 | Conn_ARM_JTAG_SWD_10 | ASSIGN |  | J6: standard ARM 10-pin SWD. | http://infocenter.arm.com/help/topic/com.arm.doc.ddi0314h/DDI0314H_coresight_components_trm.pdf
J7 | 1 | AMS | ASSIGN |  | J7: cockpit AMS lamp.
K1 | 1 | Relay_SPDT | ASSIGN | select 12 V SPDT | NO contact in the shutdown circuit; coil 12 V ~40 mA. Verify pin numbering against the ordered part.
L1,L2 | 2 | L | ASSIGN | per datasheet | L1 buck, L2 boost — values from each datasheet typical application.
Q1,Q2,Q3,Q4,Q5,Q6,Q7,Q8 | 8 | BSS138 | Package_TO_SOT_SMD:SOT-23 | BSS138 | Logic-level N-FET: relay driver, lamp driver, six balance switches. Vgs(th) low enough for 3.3 V / opto drive. | https://www.onsemi.com/pub/Collateral/BSS138-D.PDF
Q9 | 1 | AO3401A | Package_TO_SOT_SMD:SOT-23 | AO3401A | P-FET reverse-polarity blocker on the 12 V input. Vgs max ±12 V → zener clamp. | http://www.aosmd.com/pdfs/datasheet/AO3401A.pdf
R1,R2,R3,R4,R5,R6,R7,R24,R30,R34,R38,R42,R46,R50,R54,R56,R58,R60,R62,R64 | 20 | 1k | Resistor_SMD:R_0603_1608Metric |  | R1–R7 tap series (fault limit 25 mA; 2.2 k at 14S). R30… opto→gate series. R24 LED limit.
R8,R9,R22,R25,R26,R31,R35,R39,R43,R47,R51 | 11 | 100k | Resistor_SMD:R_0603_1608Metric | 0.1% for R8, R9 | R8/R9 0.1% divider (the only gain error). R22 RESET pulldown. R25/26/31… FET gate→source pulldowns.
R10,R11,R12,R15,R16,R20,R21,R27,R28,R65,R66,R67,R68,R69,R70,R71,R72,R75,R77,R79 | 20 | 10k | Resistor_SMD:R_0603_1608Metric |  | Pullups on open-collector/open-drain outputs; 1.65 V and SELFTEST dividers; TEMP_HOT pullup (R65 only — delete R66–R70).
R13 | 1 | 402 | Resistor_SMD:R_0603_1608Metric | 0.1% | R13: VREF divider top → 2.096 V (OV).
R14 | 1 | 845 | Resistor_SMD:R_0603_1608Metric | 0.1% | R14: VREF divider mid → 1.246 V (UV).
R17 | 1 | 1.24k | Resistor_SMD:R_0603_1608Metric | 0.1% | R17: VREF divider bottom. 1 mA chain so LM339 bias current gives 0.3 mV, not 3 mV.
R18 | 1 | 976 | Resistor_SMD:R_0603_1608Metric | 0.1%, 662 Ω | R18 — CHANGE TO 662 Ω for the diode-OR Vf offset (1.734 V = 57 °C).
R19 | 1 | 1.50k | Resistor_SMD:R_0603_1608Metric | 0.1% | R19: temperature threshold divider bottom.
R23,R32,R36,R40,R44,R48,R52 | 7 | 100 | Resistor_SMD:R_1206_3216Metric (bleed) / R_0603 (R23) | 1206 for bleed | Balance bleed resistors: 42 mA, 0.176 W each → 1206. R23 Q1 gate series.
R29,R33,R37,R41,R45,R49 | 6 | 470 | Resistor_SMD:R_0603_1608Metric |  | Opto LED current limit: 4.5 mA.
R53,R55,R57,R59,R61,R63 | 6 | 680 | Resistor_SMD:R_0603_1608Metric |  | Temperature sensor pull-ups — shunt reference, not NTC.
R73,R74 | 2 | 60.4 | Resistor_SMD:R_0603_1608Metric | DNP | Split CAN termination — DNP (mid-bus). Populate only at an end node.
R76 | 1 | 52.3k | Resistor_SMD:R_0603_1608Metric | 1% | R76: buck feedback top for 5 V (0.8 V ref).
R78 | 1 | 215k | Resistor_SMD:R_0603_1608Metric | 1% | R78: boost feedback top for 28 V (1.233 V ref).
R80 | 1 | 0 | Resistor_SMD:R_0603_1608Metric |  | R80: single GNDA↔GND link — the star point, adjacent to FB1.
SW1 | 1 | SW_Push | Button_Switch_SMD:SW_SPST_PTS645 |  | Manual latch reset — the only reset (EV 6.1.6).
U1,U2 | 2 | ADG1408YRUZ | Package_SO:TSSOP-16_4.4x5mm_P0.65mm | ADG1408YRUZ | 8:1 mux; break-before-make so two taps are never bridged through C1. 36 V max — replace with TMUX8108 (100 V) at 14S. | https://www.analog.com/media/en/technical-documentation/data-sheets/ADG1408_1409.pdf
U3 | 1 | 74LVC1G10 | Package_TO_SOT_SMD:SOT-23-5 | SN74LVC1G10DBV | 3-input NAND → /ADDR7. Detects the read slot. | http://www.ti.com/lit/sg/scyt129e/scyt129e.pdf
U4 | 1 | LM339 | Package_SO:SOIC-14_3.9x8.7mm_P1.27mm | LM339DT | Quad comparator, open-collector: OV, UV, OT, watchdog inverter. Wired-OR outputs; 5 V supply for input range, pullups to 3.3 V level-shift for free. | https://www.st.com/resource/en/datasheet/lm139.pdf
U5,U7,U8 | 3 | 74LVC1G02 | Package_TO_SOT_SMD:SOT-23-5 | SN74LVC1G02DBV | NOR: address gate (U5) and SR latch (U7/U8). NOR = AND of two active-low signals. | https://www.ti.com/lit/ds/symlink/sn74lvc1g02.pdf
U6,U11 | 2 | 74LVC1G32 | Package_TO_SOT_SMD:SOT-23-5 | SN74LVC1G32DBV | OR tree merging the four fault sources into SET. | http://www.ti.com/lit/sg/scyt129e/scyt129e.pdf
U9 | 1 | TPS3823-33DBV | Package_TO_SOT_SMD:SOT-23-5 | TPS3823-33DBVR | Watchdog supervisor; open-drain RESET into the OR tree. Kick every 20 ms; check MIN timeout. | https://www.ti.com/lit/ds/symlink/tps3823.pdf
U10 | 1 | ADR4525 | Package_SO:SOIC-8_3.9x4.9mm_P1.27mm | ADR4525BRZ | 2.500 V reference: source of every comparator threshold and the value the ADC scale is corrected against (LQFP64 has no VREF+). | https://www.analog.com/media/en/technical-documentation/data-sheets/ADR4520_4525_4530_4533_4540_4550.pdf
U12,U13,U14,U15,U16,U17 | 6 | LTV-817S | Package_DIP:SMDIP-4_W9.53mm | LTV-817S | Optocoupler per balance channel: level-shifts a ground-referenced GPIO to a FET whose source sits up to 21 V (54 V at 14S) above ground. | http://www.us.liteon.com/downloads/LTV-817-827-847.PDF
U18 | 1 | STM32F446RETx | Package_QFP:LQFP-64_10x10mm_P0.5mm | STM32F446RET6 | LQFP64. 16 ADC channels; WDT_KICK is a firmware GPIO, not a timer. | https://www.st.com/resource/en/datasheet/stm32f446re.pdf
U19 | 1 | TJA1051T-3 | Package_SO:SOIC-8_3.9x4.9mm_P1.27mm | TJA1051T/3 | CAN transceiver; VIO pin = 3.3 V logic side with 5 V bus side, no level shifters. S pin tied low. | http://www.nxp.com/docs/en/data-sheet/TJA1051.pdf
U20 | 1 | AP63203WU | Package_TO_SOT_SMD:TSOT-23-6 | AP63203WU-7 | Synchronous buck 12 V → 5 V; no catch diode. FB ref 0.8 V. | https://www.diodes.com/assets/Datasheets/AP63200-AP63201-AP63203-AP63205.pdf
U21 | 1 | MIC5219-3.3YM5 | Package_TO_SOT_SMD:SOT-23-5 | MIC5219-3.3YM5-TR | Low-noise LDO 5 V → 3.3 V; strips buck switching noise before the analog section. BYP cap required. | http://ww1.microchip.com/downloads/en/DeviceDoc/MIC5219-500mA-Peak-Output-LDO-Regulator-DS20006021A.pdf
U22 | 1 | TPS61040DBV | Package_TO_SOT_SMD:SOT-23-5 | TPS61040DBVR | Boost for the mux rail (28 V at 6S). FB ref 1.233 V. Tops out at 28 V — different part needed for 65 V at 14S. | http://www.ti.com/lit/ds/symlink/tps61040.pdf

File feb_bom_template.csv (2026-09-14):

Qty (for 1 board) | Manufacturer Part # | Price/unit ($) | Purchase URL | Reference Designator | Description (include component value if applicable) | Datasheet Link
2 | ADG1408YRUZ |  |  | U1, U2 | 8:1 analog multiplexer, break-before-make, TSSOP-16 — flying-cap front end (36 V max; TMUX8108 at 14S) | https://www.analog.com/media/en/technical-documentation/data-sheets/ADG1408_1409.pdf
1 | LM339DT |  |  | U4 | Quad comparator, open-collector, SOIC-14 — OV/UV/OT/watchdog inverter | https://www.st.com/resource/en/datasheet/lm139.pdf
1 | SN74LVC1G10DBVR |  |  | U3 | 3-input NAND, SOT-23-6 — address decode /ADDR7 | https://www.ti.com/lit/ds/symlink/sn74lvc1g10.pdf
3 | SN74LVC1G02DBVR |  |  | U5, U7, U8 | 2-input NOR, SOT-23-5 — address gate + SR latch | https://www.ti.com/lit/ds/symlink/sn74lvc1g02.pdf
2 | SN74LVC1G32DBVR |  |  | U6, U11 | 2-input OR, SOT-23-5 — fault OR tree | https://www.ti.com/lit/ds/symlink/sn74lvc1g32.pdf
1 | TPS3823-33DBVR |  |  | U9 | Watchdog supervisor 3.3 V, SOT-23-5 | https://www.ti.com/lit/ds/symlink/tps3823.pdf
1 | ADR4525BRZ |  |  | U10 | 2.500 V precision voltage reference, SOIC-8 | https://www.analog.com/media/en/technical-documentation/data-sheets/ADR4520_4525_4530_4533_4540_4550.pdf
1 | STM32F446RET6 |  |  | U18 | Cortex-M4 MCU, 512 KB flash, LQFP-64 | https://www.st.com/resource/en/datasheet/stm32f446re.pdf
1 | TJA1051T/3,118 |  |  | U19 | CAN transceiver with 3.3 V VIO, SOIC-8 | https://www.nxp.com/docs/en/data-sheet/TJA1051.pdf
1 | AP63203WU-7 |  |  | U20 | Synchronous buck 12 V→5 V, 2 A, TSOT-26 | https://www.diodes.com/assets/Datasheets/AP63200-AP63201-AP63203-AP63205.pdf
1 | MIC5219-3.3YM5-TR |  |  | U21 | Low-noise LDO 5 V→3.3 V, 500 mA, SOT-23-5 | https://ww1.microchip.com/downloads/en/DeviceDoc/MIC5219-500mA-Peak-Output-LDO-Regulator-DS20006021A.pdf
1 | TPS61040DBVR |  |  | U22 | Boost converter 12 V→28 V for mux rail, SOT-23-5 | https://www.ti.com/lit/ds/symlink/tps61040.pdf
6 | LTV-817S |  |  | U12–U17 | Optocoupler, 1-ch, SMD-4 — isolated balance FET gate drive | http://www.us.liteon.com/downloads/LTV-817-827-847.PDF
8 | BSS138 |  |  | Q1–Q8 | N-MOSFET logic-level 50 V 220 mA SOT-23 — relay, lamp, 6× balance | https://www.onsemi.com/pub/Collateral/BSS138-D.PDF
1 | AO3401A |  |  | Q9 | P-MOSFET 30 V 4 A SOT-23 — reverse-polarity blocker | http://www.aosmd.com/pdfs/datasheet/AO3401A.pdf
1 | BAT54S-7-F |  |  | D1 | Dual Schottky series SOT-23 — VCELL ADC pin clamp | https://www.diodes.com/assets/Datasheets/ds11005.pdf
1 | 1N4148W-7-F |  |  | D2 | Switching diode SOD-123 — relay coil flyback | https://www.diodes.com/assets/Datasheets/ds30086.pdf
3 | BAT54A-7-F |  |  | D3, D4, D5 | Dual Schottky common-anode SOT-23 — temperature diode-OR | https://www.diodes.com/assets/Datasheets/ds11005.pdf
1 | PESD1CAN,215 |  |  | D9 | Dual TVS for CAN bus, SOT-23 — at J3 | https://assets.nexperia.com/documents/data-sheet/PESD1CAN.pdf
1 | MMSZ5242B-7-F |  |  | D10 | Zener 12 V SOD-123 — Q9 gate-source clamp | https://www.diodes.com/assets/Datasheets/ds18010.pdf
1 | SMAJ16A |  |  | D11 | TVS unidirectional 16 V standoff, SMA — 12 V input load dump | https://www.littelfuse.com/media?itemid=75e32973-b177-4ee3-a0ff-cedaf1abdb93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
1 | SS14 |  |  | D12 | Schottky 40 V 1 A SMA — boost rectifier | https://www.vishay.com/docs/88746/ss12.pdf
1 | C1210C105J5GACTU |  |  | C1 | 1 µF 50 V C0G 1210 — FLYING CAPACITOR (C0G mandatory) | https://content.kemet.com/datasheets/KEM_C1002_X7R_SMD.pdf
30 | CL10B104KB8NNNC |  |  | C5–C8, C10–C25, C28, C30, C32, C33, C35, C37–C39, C43, C51 | 100 nF 50 V X7R 0603 — decoupling | https://product.samsungsem.com/mlcc/CL10B104KB8NNN.do
10 | CL21A106KOQNNNE |  |  | C3, C4, C9, C26, C27, C29, C31, C41, C42, C50 | 10 µF 16 V X5R 0805 — bulk | https://product.samsungsem.com/mlcc/CL21A106KOQNNN.do
4 | CL10A105KB8NNNC |  |  | C34, C45, C48, C49 | 1 µF 50 V X5R 0603 — VDDA / regulator I/O (C49: use 100 V-rated part for 28 V boost output) | https://product.samsungsem.com/mlcc/CL10A105KB8NNN.do
2 | CL10A225KP8NNNC |  |  | C36, C47 | 2.2 µF 10 V X5R 0603 — VCAP_1, LDO output | https://product.samsungsem.com/mlcc/CL10A225KP8NNN.do
1 | CL31A226KAHNNNE |  |  | C44 | 22 µF 25 V X5R 1206 — buck output | https://product.samsungsem.com/mlcc/CL31A226KAHNNN.do
1 | CL10C101JB8NNNC |  |  | C2 | 100 pF 50 V C0G 0603 — VCELL ADC node | https://product.samsungsem.com/mlcc/CL10C101JB8NNN.do
1 | CL10B471KB8NNNC |  |  | C46 | 470 pF 50 V X7R 0603 — MIC5219 BYP | https://product.samsungsem.com/mlcc/CL10B471KB8NNN.do
19 | RC0603FR-071KL |  |  | R1–R7, R30, R34, R38, R42, R46, R50, R54, R56, R58, R60, R62, R64 | 1 kΩ 1% 0603 — tap series (fault limit), opto→gate series, temp RC | https://www.yageo.com/upload/media/product/products/datasheet/rchip/PYu-RC_Group_51_RoHS_L_12.pdf
1 | RC0805FR-071KL |  |  | R24 | 1 kΩ 1% 0805 — AMS lamp current limit (0.1 W) | https://www.yageo.com/upload/media/product/products/datasheet/rchip/PYu-RC_Group_51_RoHS_L_12.pdf
2 | RT0603BRD07100KL |  |  | R8, R9 | 100 kΩ 0.1% 0603 — VCELL 2:1 divider (sets gain) | https://www.yageo.com/upload/media/product/products/datasheet/rchip/PYu-RT_1-to-0.01_RoHS_L_12.pdf
9 | RC0603FR-07100KL |  |  | R22, R25, R26, R31, R35, R39, R43, R47, R51 | 100 kΩ 1% 0603 — RESET pulldown, FET gate–source pulldowns | https://www.yageo.com/upload/media/product/products/datasheet/rchip/PYu-RC_Group_51_RoHS_L_12.pdf
15 | RC0603FR-0710KL |  |  | R10–R12, R15, R16, R20, R21, R27, R28, R65, R71, R72, R75, R77, R79 | 10 kΩ 1% 0603 — pullups, 1.65 V / SELFTEST dividers, feedback bottoms | https://www.yageo.com/upload/media/product/products/datasheet/rchip/PYu-RC_Group_51_RoHS_L_12.pdf
1 | RT0603BRD07402RL |  |  | R13 | 402 Ω 0.1% 0603 — VREF threshold chain (OV tap) | https://www.yageo.com/upload/media/product/products/datasheet/rchip/PYu-RT_1-to-0.01_RoHS_L_12.pdf
1 | RT0603BRD07845RL |  |  | R14 | 845 Ω 0.1% 0603 — VREF threshold chain (UV tap) | https://www.yageo.com/upload/media/product/products/datasheet/rchip/PYu-RT_1-to-0.01_RoHS_L_12.pdf
1 | RT0603BRD071K24L |  |  | R17 | 1.24 kΩ 0.1% 0603 — VREF threshold chain bottom | https://www.yageo.com/upload/media/product/products/datasheet/rchip/PYu-RT_1-to-0.01_RoHS_L_12.pdf
1 | RT0603BRD07662RL |  |  | R18 | 662 Ω 0.1% 0603 — overtemp threshold top (1.734 V) | https://www.yageo.com/upload/media/product/products/datasheet/rchip/PYu-RT_1-to-0.01_RoHS_L_12.pdf
1 | RT0603BRD071K5L |  |  | R19 | 1.5 kΩ 0.1% 0603 — overtemp threshold bottom | https://www.yageo.com/upload/media/product/products/datasheet/rchip/PYu-RT_1-to-0.01_RoHS_L_12.pdf
6 | RC1206FR-07100RL |  |  | R32, R36, R40, R44, R48, R52 | 100 Ω 1% 1206 — balance bleed (0.176 W each) | https://www.yageo.com/upload/media/product/products/datasheet/rchip/PYu-RC_Group_51_RoHS_L_12.pdf
1 | RC0603FR-07100RL |  |  | R23 | 100 Ω 1% 0603 — Q1 gate series | https://www.yageo.com/upload/media/product/products/datasheet/rchip/PYu-RC_Group_51_RoHS_L_12.pdf
6 | RC0603FR-07470RL |  |  | R29, R33, R37, R41, R45, R49 | 470 Ω 1% 0603 — opto LED current limit | https://www.yageo.com/upload/media/product/products/datasheet/rchip/PYu-RC_Group_51_RoHS_L_12.pdf
6 | RC0603FR-07680RL |  |  | R53, R55, R57, R59, R61, R63 | 680 Ω 1% 0603 — temperature sensor pull-ups | https://www.yageo.com/upload/media/product/products/datasheet/rchip/PYu-RC_Group_51_RoHS_L_12.pdf
1 | RC0603FR-0752K3L |  |  | R76 | 52.3 kΩ 1% 0603 — buck feedback top (5 V) | https://www.yageo.com/upload/media/product/products/datasheet/rchip/PYu-RC_Group_51_RoHS_L_12.pdf
1 | RC0603FR-07215KL |  |  | R78 | 215 kΩ 1% 0603 — boost feedback top (28 V) | https://www.yageo.com/upload/media/product/products/datasheet/rchip/PYu-RC_Group_51_RoHS_L_12.pdf
1 | RC0603JR-070RL |  |  | R80 | 0 Ω 0603 — GNDA↔GND star-point link | https://www.yageo.com/upload/media/product/products/datasheet/rchip/PYu-RC_Group_51_RoHS_L_12.pdf
1 | 0ZCG0050AF2C |  |  | F1 | PTC resettable fuse 500 mA 1812 — 12 V input | https://www.belfuse.com/resources/datasheets/circuitprotection/ds-cp-0zcg-series.pdf
1 | BLM21PG221SN1D |  |  | FB1 | Ferrite bead 220 Ω @100 MHz 0805 — +3.3V→+3.3VA | https://www.murata.com/products/productdetail?partno=BLM21PG221SN1%23
1 | G5V-1 DC12 |  |  | K1 | Signal relay SPDT 12 V coil — NO contact in shutdown circuit (verify SDC current vs 1 A rating) | https://omronfs.omron.com/en_US/ecb/products/pdf/en-g5v_1.pdf
1 | PTS645SM43SMTR92 LFS |  |  | SW1 | Tactile pushbutton SMD — manual latch reset | https://www.ckswitches.com/media/1471/pts645.pdf
1 | ABLS-8.000MHZ-B4-T |  |  | Y1 | Crystal 8 MHz HC-49/US SMD — HSE for CAN timing (not yet in schematic) | https://abracon.com/Resonators/ABLS.pdf
2 | CL10C180JB8NNNC |  |  | C52, C53 | 18 pF 50 V C0G 0603 — crystal load caps (not yet in schematic) | https://product.samsungsem.com/mlcc/CL10C180JB8NNN.do
1 | TBD — 4.7 µH shielded, ≥2 A sat (per AP63203 datasheet) |  |  | L1 | Buck inductor — value/part from AP63203 typical application | https://www.diodes.com/assets/Datasheets/AP63200-AP63201-AP63203-AP63205.pdf
1 | TBD — 10 µH, ≥400 mA sat (per TPS61040 datasheet) |  |  | L2 | Boost inductor — value/part from TPS61040 typical application | https://www.ti.com/lit/ds/symlink/tps61040.pdf
1 | FTSH-105-01-L-DV-K |  |  | J6 | ARM Cortex 10-pin SWD header, 1.27 mm, shrouded | https://suddendocs.samtec.com/catalog_english/ftsh_smt.pdf
2 | TBD — Molex DuraClik 7-ckt vertical header |  |  | J1, J2 | 7-pin keyed locking connectors: cell taps (rated for 42 mA balance current), temperature sensors | https://www.molex.com/en-us/products/connectors/wire-to-board-connectors/duraclik-connectors
1 | TBD — 5-ckt locking header |  |  | J3 | CAN + 12 V LV: +12V, GND, CANH, CANL, shield
3 | TBD — 2-ckt locking header |  |  | J4, J5, J7 | 12 V in / shutdown-circuit pass-through / AMS cockpit lamp

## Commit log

2026-09-08 protection; frontend; highlevel arch done
    [balance.kicad_sch, can.kicad_sch, feb-bms.kicad_pcb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]
2026-09-09 can transceiver; power; mcu
    [can.kicad_sch, feb-bms.kicad_sch, frontend.kicad_sch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]
2026-09-14 Add presentation (slides, PDF, pptx) and latest schematic edits
    [bom.csv, can.kicad_sch, differential-sensing.kicad_sch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]
